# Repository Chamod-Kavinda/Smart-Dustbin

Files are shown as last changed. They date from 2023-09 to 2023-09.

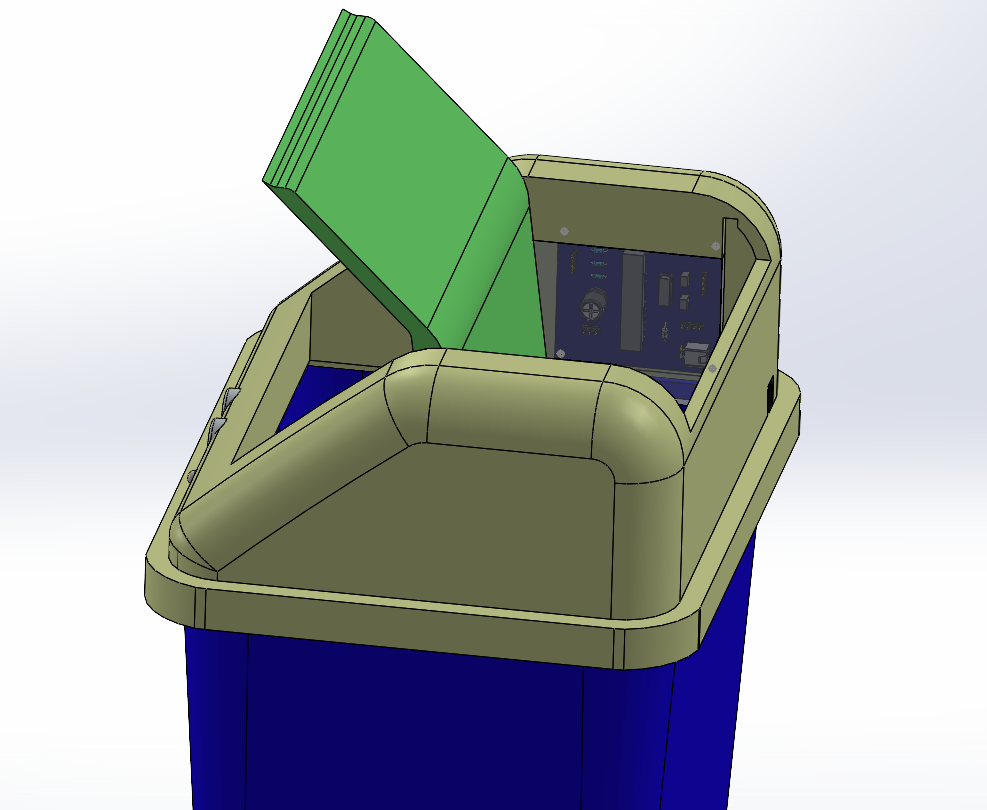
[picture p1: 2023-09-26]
Enclosure Design files/3D Design/A3.png

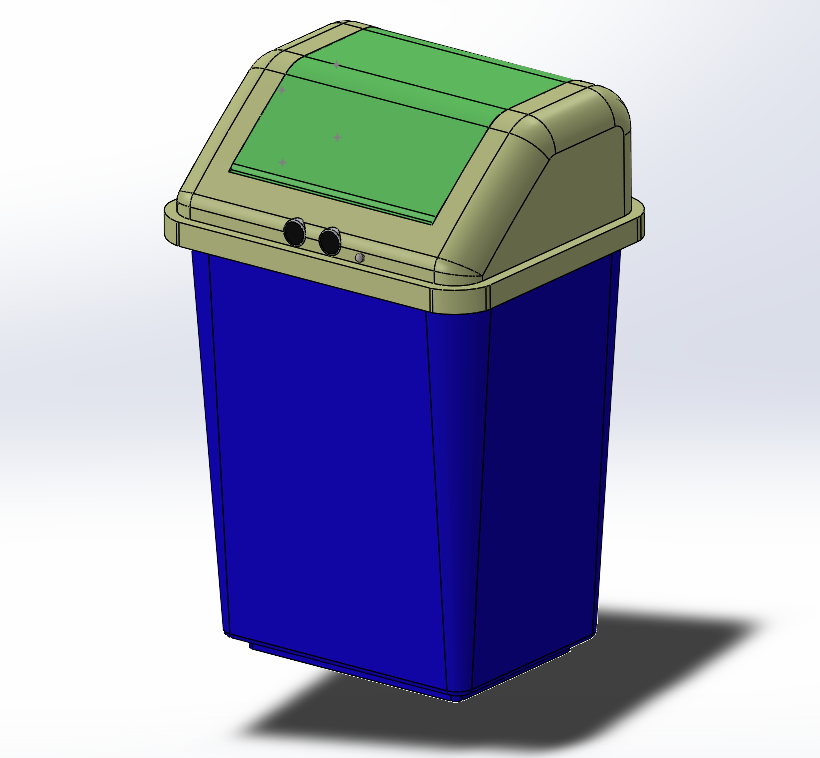
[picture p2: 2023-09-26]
Enclosure Design files/3D Design/A1.png

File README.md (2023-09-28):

# Smart Dustbin

## Introduction

The Smart Dustbin is an innovative waste management solution designed to provide convenience, hygiene, and sustainability in managing waste. This project utilizes ultrasonic sensors, a microcontroller, an RGB LED, and a servo motor to create a smart dustbin that opens automatically when someone approaches and alerts users when it's time to empty it.

## Features

- **Automatic Lid Opening**: The dustbin's lid opens automatically when a user approaches, reducing the need for physical contact and promoting hygiene.

- **Garbage Fill Level Indicator**: An RGB LED indicates the garbage fill level with colors (green, yellow, and red) so users know when it's time to empty the bin.

- **Manual Override**: Users can manually open and close the lid if needed.

[Final Report](https://github.com/Chamod-Kavinda/Smart-Dustbin/blob/main/Final%20Report.pdf)

### Schematic Design
Schematic

### PCB Design
pcb

### Solidwork Designs
Solidwork Design

### Final Product
Final Product

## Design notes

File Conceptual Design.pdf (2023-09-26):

## Department of Electronic and Telecommunication Engineering University of Moratuwa

## EN2160 – Electronic Design Realization


## Conceptual Design Report – Smart Dustbin

Name: Kavinda W.M.C.

### Index Number: 200301D

### 7th of June 2023

### 1. Introducon

This report presents the conceptual design of a smart dustbin, an innovave soluon that incorporates advanced technology for automac opening and closing. The aim of this design is to provide users with a convenient and hygienic waste disposal experience. By eliminang the need for manual operaon, the smart dustbin enhances efficiency and user convenience. This brief introducon provides an overview of the report, which explores the enclosure design and block diagrams, highlighng the importance of user feedback and customizaon opons. The report serves as a foundaon for further development, showcasing the potenal of the smart dustbin to revoluonize waste management.

### 2. List of members who contributed to the Design Driven Innovaon

1. Anuki Pasqual | 200445V
2. Tharusha Pathirana | 200449L
3. Navindu Gunawardena | 200201V
4. Peshala Gunathilaka | 200439G
5. Lasitha Jananjaya | 200650U
6. Chehal Jayasuriya | 200262G
7. Malanban Kuganenthiran 200373X

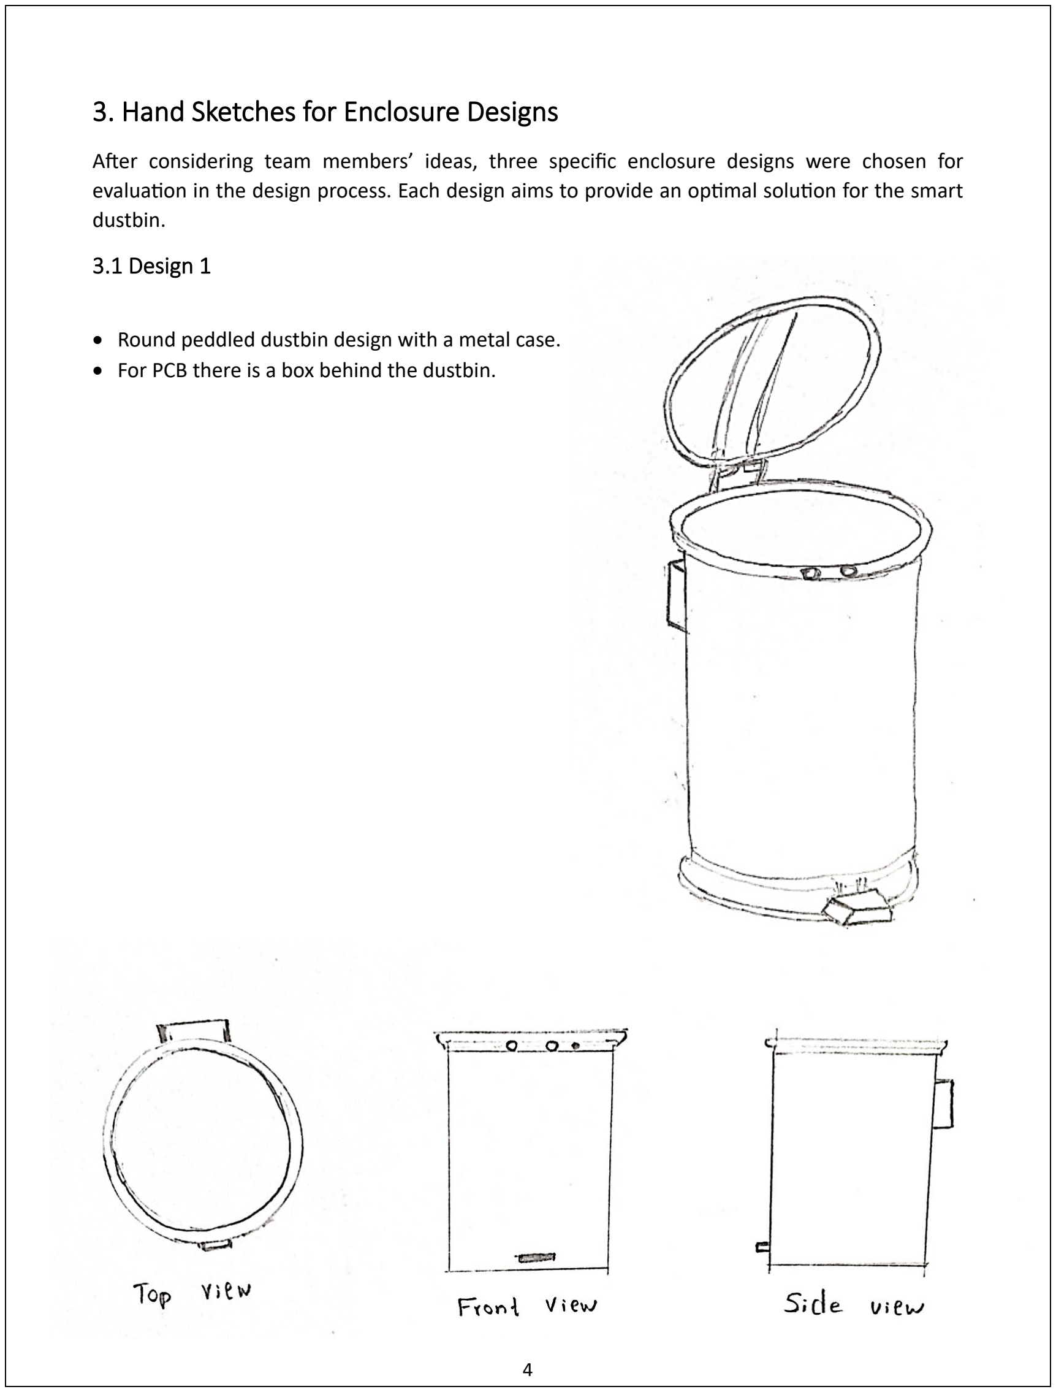
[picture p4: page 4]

### 3. Hand Sketches for Enclosure Designs

Aer considering team members’ ideas, three specific enclosure designs were chosen for evaluaon in the design process. Each design aims to provide an opmal soluon for the smart dustbin.
3.1 Design 1
- Round peddled dustbin design with a metal case.
- For PCB there is a box behind the dustbin.

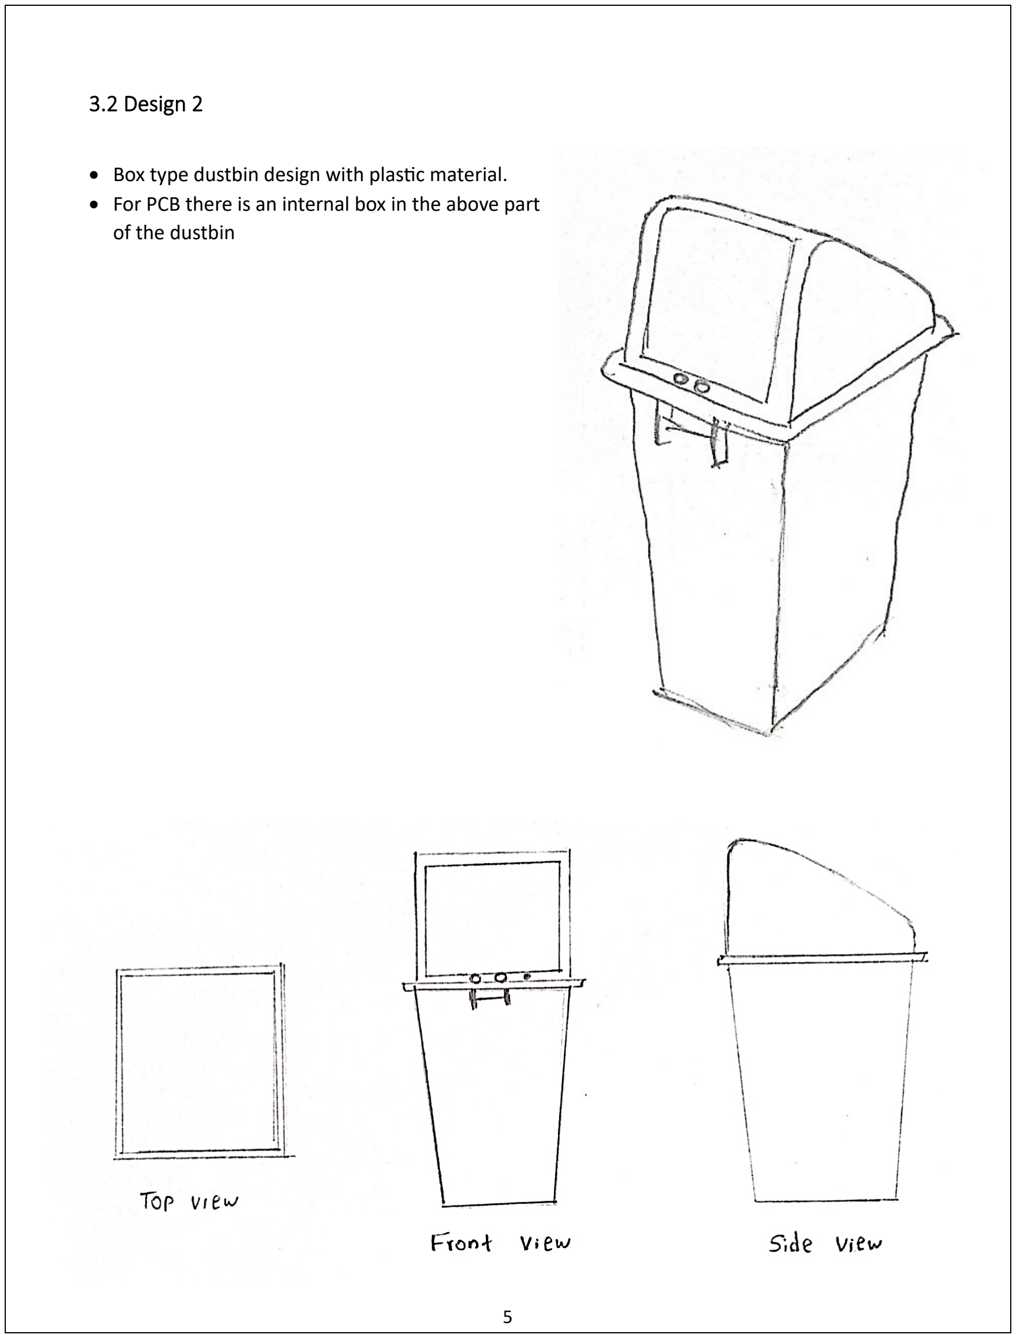
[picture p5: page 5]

3.2 Design 2

- Box type dustbin design with plasc material.
- For PCB there is an internal box in the above part of the dustbin

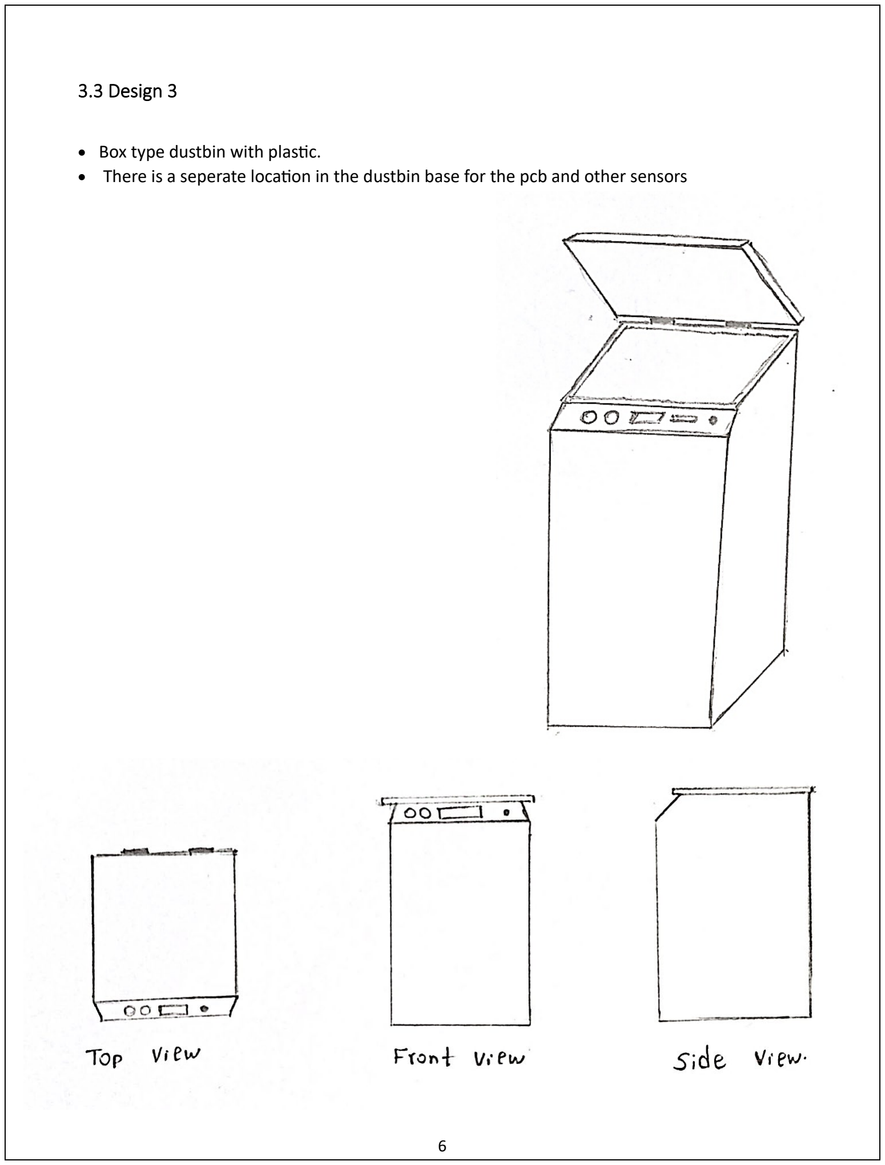
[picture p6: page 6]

3.3 Design 3

- Box type dustbin with plasc.
- There is a seperate locaon in the dustbin base for the pcb and other sensors

### 4. Block Diagrams for Circuit Designs

In the smart dustbin project context, there are opons to consider for the circuit design: power supply, sensor technologies, and lid opening mechanisms. These opons were thoroughly reviewed and evaluated with the group, considering the specific components required and the desired funconality of the smart dustbin. The group's careful assessment allowed for the selecon of the most suitable opons that align with the project's design goals and objecves. 4.1 Design 1

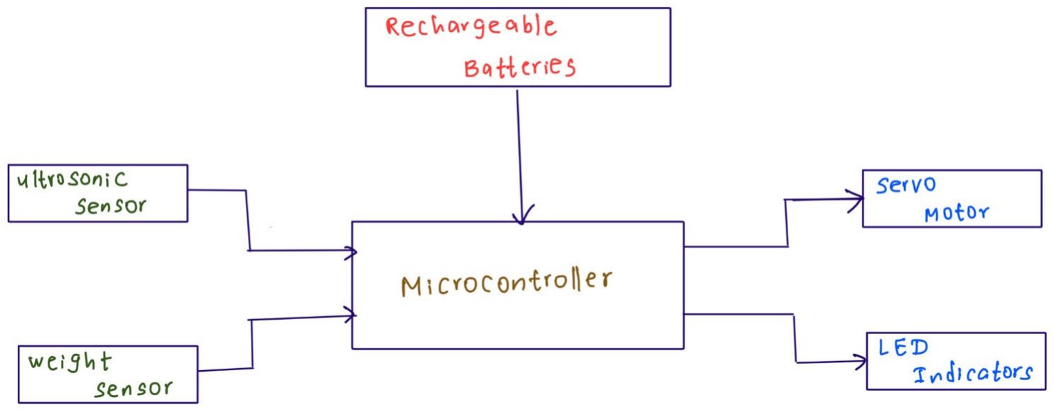
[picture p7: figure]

- Newly added: Rechargeable bateries as a power source. Weight sensor for measuring the content of the bin.
- Removed: One ultrasonic sensor

4.2 Design 2

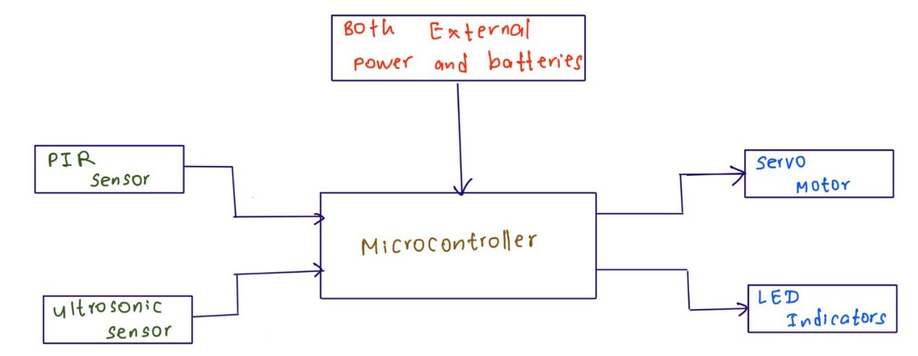
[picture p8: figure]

- Newly added: Bateries as a power source. PIR sensor for moon detecon.
- Removed: One ultrasonic sensor

4.3 Design 3

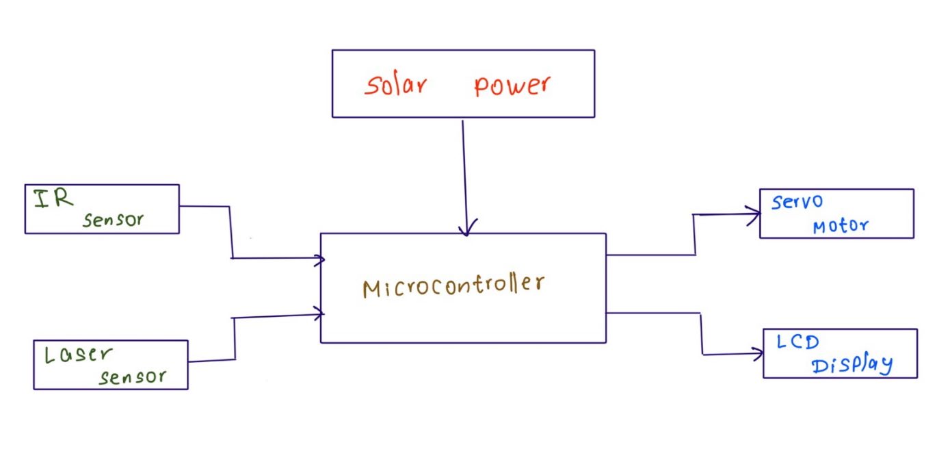
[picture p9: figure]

- Newly added: Solar power as the primary power source. IR sensor for moon detecon.
Laser sensor for measuring the content of the bin.
- Removed: | Two ultrasonic sensors
| External power source
| LED indicators

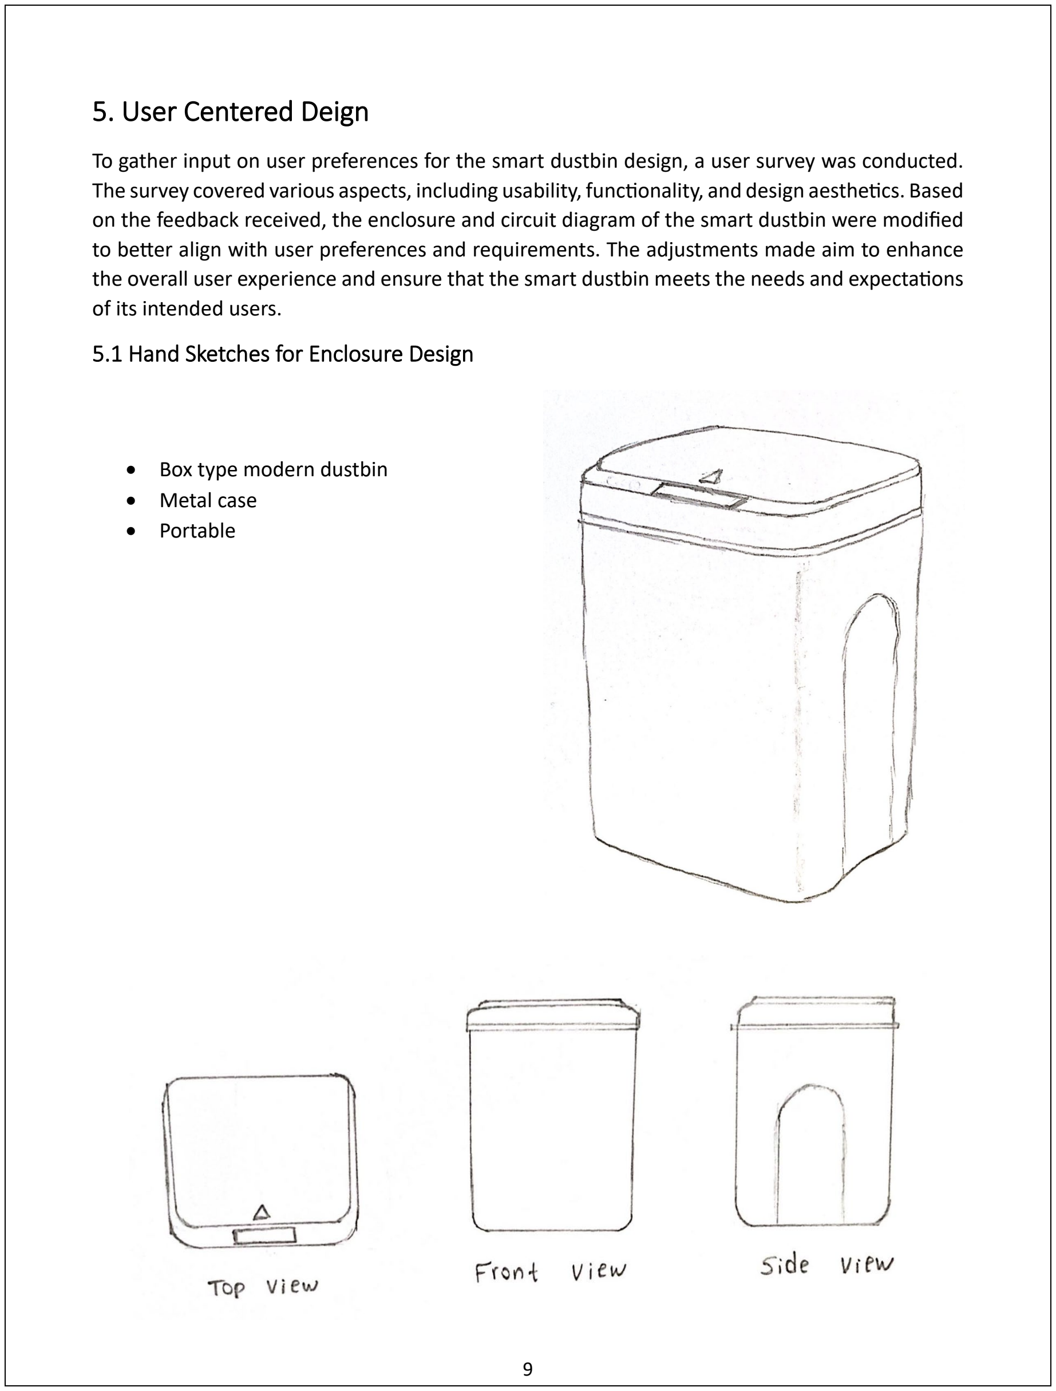
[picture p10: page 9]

### 5. User Centered Deign

To gather input on user preferences for the smart dustbin design, a user survey was conducted. The survey covered various aspects, including usability, funconality, and design aesthecs. Based on the feedback received, the enclosure and circuit diagram of the smart dustbin were modified to beter align with user preferences and requirements. The adjustments made aim to enhance the overall user experience and ensure that the smart dustbin meets the needs and expectaons of its intended users.
5.1 Hand Sketches for Enclosure Design
- Box type modern dustbin
- Metal case
- Portable

5.2 Block Diagram for Circuit Design

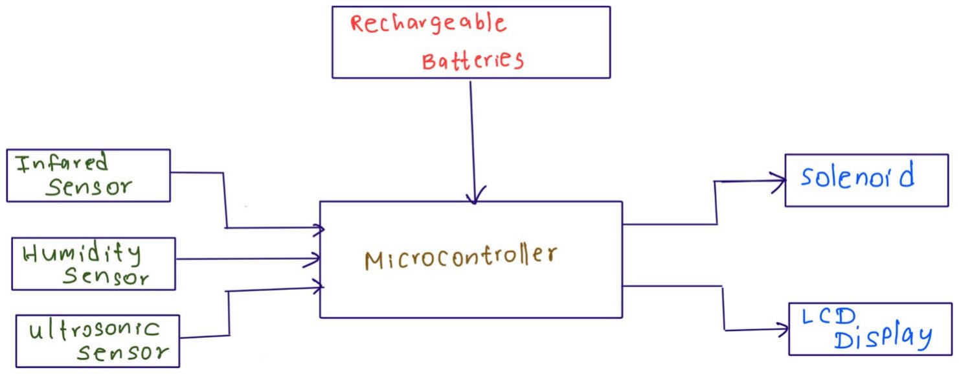
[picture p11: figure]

- Newly added: Rechargeable bateries. IR sensor for moon detecon.
Ultrasonic sensor for measuring the content of the bin. Solenoid for lid open mechanism
- Removed: | Two ultrasonic sensors
| External power source
| LED indicators
| Servo motor

### 6. Selecon Matrix

6.1 Evaluaon Criteria for Enclosures
1. Aesthecs: Assess the visual appeal and overall design harmony of the enclosure.
2. Funconality: Evaluate how well the enclosure accommodates the waste disposal process and ease of use.
3. Durability: Examine the materials and construcon of the enclosure for long-lasng performance and resistance to wear and tear.
4. Weather Resistance: Consider the enclosure's ability to withstand outdoor condions, such as rain, sunlight, and temperature fluctuaons.
5. Accessibility: Evaluate how easily users can interact with the smart dustbin, including opening and closing mechanisms, sensor placement, and user interface.
6. Size and Space Efficiency: Assess the enclosure's dimensions in relaon to the available space for placement and storage efficiency.
7. Safety: Consider any safety features incorporated into the enclosure design, such as childproof mechanisms or sensor-based obstacle detecon.
8. Integraon: Evaluate how well the enclosure design integrates with the surrounding environment, whether it is a residenal, commercial, or public seng.

The following Table depicts the marks given for each point (out of 10)
Criteria | Design 1 | Design 2 | Design 3 | User Centered Design
Aesthecs | 8 | 7 | 6 | 9
Funconality | 7 | 6 | 7 | 8
Durability | 7 | 8 | 9 | 7
Weather Resistance | 7 | 8 | 7 | 7
Accessibility | 6 | 8 | 8 | 9
Size and Space Efficiency | 9 | 6 | 7 | 9
Safety | 5 | 6 | 7 | 8
Integraon | 6 | 7 | 9 | 8
Total Marks | 55 | 56 | 60 | 65

Based on the aforemenoned criteria, it is evident that the user centered design received the highest score, making it the selected choice to proceed.

6.2 Evaluaon Criteria for Circuit Design
1. Funconality: Assess the overall funconality and performance of the circuit design, ensuring that it accurately detects and responds to the waste disposal requirements.
2. Power Efficiency: Evaluate the circuit design's power consumpon and efficiency to ensure opmal energy usage and batery life.
3. Sensor Integraon: Assess how well the circuit design integrates and interfaces with the various sensors used in the smart dustbin, such as ultrasonic sensors, weight sensors, or proximity sensors.
4. Communicaon: Evaluate the communicaon protocols and interfaces used in the circuit design, ensuring seamless data transmission between the sensors, microcontroller, and other components.
5. Safety: Consider any safety features implemented in the circuit design, such as overcurrent protecon, voltage regulaon, or short-circuit prevenon mechanisms.
6. Reliability: Evaluate the reliability and robustness of the circuit design to ensure consistent and accurate performance under different operang condions.
7. Scalability: Assess the circuit design's ability to accommodate future upgrades or addions, allowing for potenal expansion or integraon of addional features.
8. Cost-effecveness: Consider the overall cost of the circuit design, including component selecon and manufacturing consideraons, to ensure a balance between funconality and affordability.

The following Table depicts the marks given for each point (out of 10)
Criteria | Design 1 | Design 2 | Design 3 | User Centered Design
Funconality | 8 | 7 | 8 | 9
Power Efficiency | 7 | 9 | 5 | 7
Sensor Integraon | 6 | 7 | 8 | 9
Communicaon | 8 | 8 | 8 | 8
Safety | 8 | 8 | 6 | 9
Reliability | 6 | 6 | 8 | 9
Scalability | 9 | 9 | 9 | 8
Cost-effecveness | 7 | 8 | 6 | 5
Total Marks | 59 | 62 | 58 | 64

Based on the aforemenoned criteria, it is evident that the user centered design received the highest score, making it the selected choice to proceed.

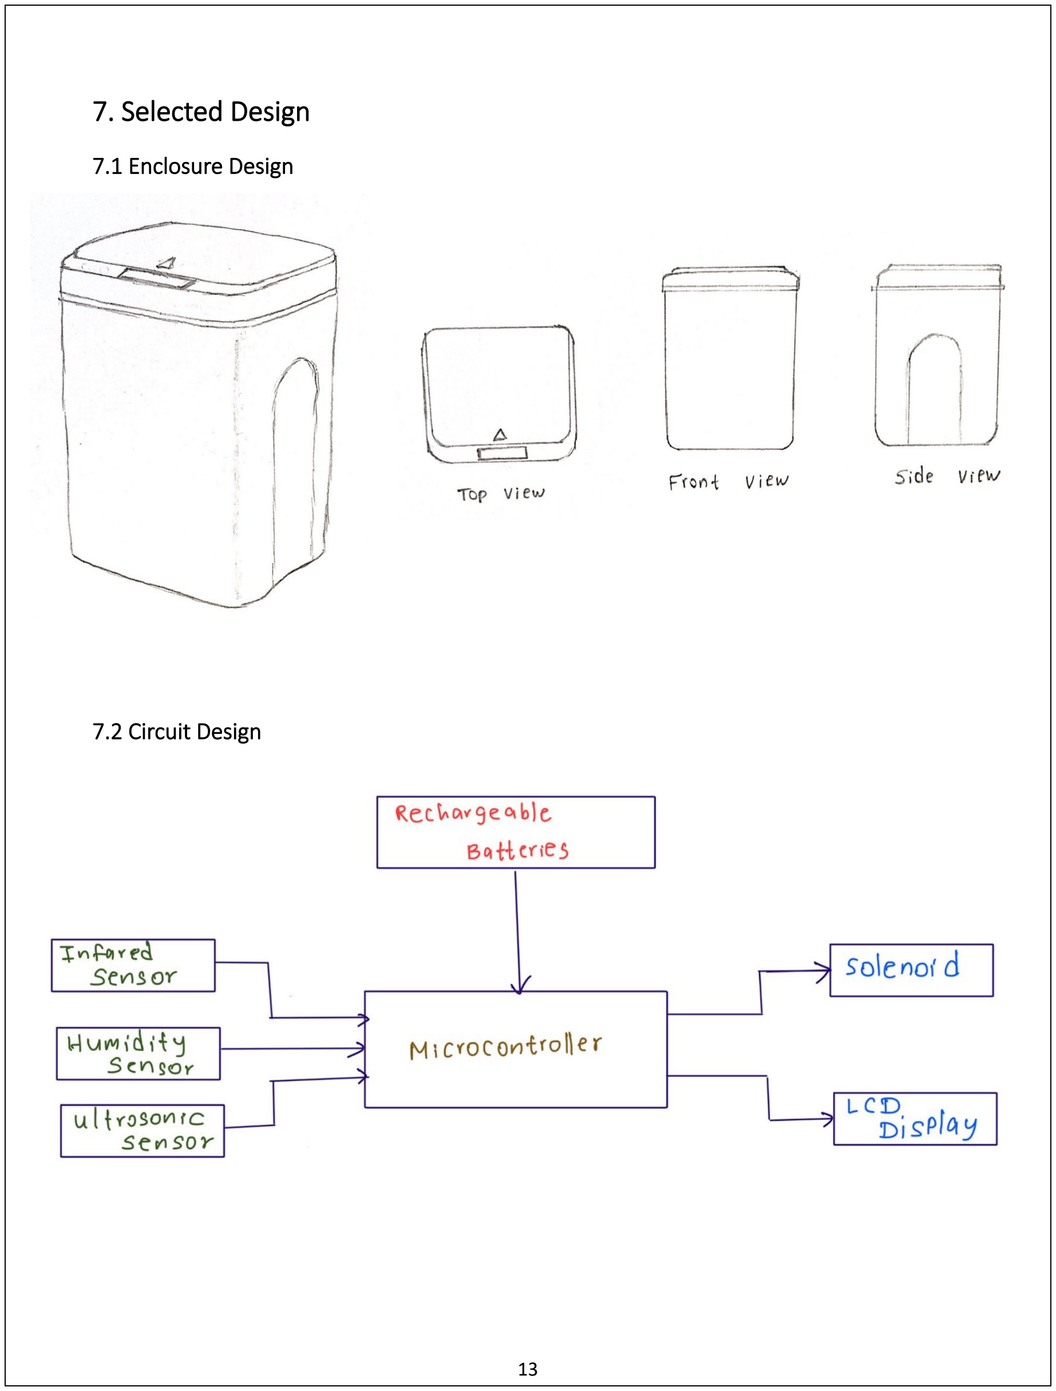
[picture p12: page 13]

### 7. Selected Design

7.1 Enclosure Design

7.2 Circuit Design

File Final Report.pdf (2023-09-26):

## Department of Electronic and Telecommunication Engineering University of Moratuwa

## EN2160 – Electronic Design Realization


## Final Report – Smart Dustbin

Name: Kavinda W.M.C.

### Index Number: 200301D

| 25th of July 2023

### Table of Contents

### Abstract

The Smart Dustbin project introduces an innovave waste management soluon designed to enhance convenience, hygiene, and sustainability. This project focuses on creang a dustbin with automac opening and a level sensor, revoluonizing the tradional waste disposal process. By incorporang ultrasonic sensor technology, the smart dustbin can detect proximity and trigger the lid to open automacally when someone approaches, reducing physical contact and promong sanitaon. Addionally, the bin ulizes a level sensor to connually monitor the garbage level and indicate to the user when it approaches full capacity, prevenng overfilling. This report presents the development and features of the smart dustbin, highlighng its contribuons to a cleaner and healthier environment while making waste disposal an efficient and hands-free experience.

### Introducon

In a world increasingly focused on sustainability and improved quality of life, waste management emerges as a crucial challenge. Tradional waste disposal methods and convenonal dustbins have long served their purpose, but they lack the efficiency and convenience required for modern living. To address this need, the Smart Dustbin project introduces an innovave soluon that elevates waste management to new heights.
The primary goal of this project is to develop a smart dustbin that offers a hands-free, hygienic, and sustainable approach to waste disposal. By incorporang advanced sensor technology, the smart dustbin opens automacally when a user approaches, reducing physical contact and minimizing the risk of contaminaon. An ultrasonic sensor serves as the key element for detecng proximity and triggering the lid's smooth and gradual opening.
Furthermore, the smart dustbin boasts a level sensor that constantly monitors the garbage fill level with remarkable accuracy and reliability. LED indicators change color as the garbage level increases, providing users with a visual cue for mely waste disposal and prevenng overfilling. This report delves into the design, development, and features of the smart dustbin, highlighng its potenal to transform waste management pracces. By promong touchless interacon, reducing waste overflow, and encouraging responsible waste disposal habits, the smart dustbin takes a significant step toward a cleaner, healthier, and more sustainable future.

### 1. Product Descripon and Specificaons

The Smart Dustbin is a revoluonary waste management soluon designed to offer convenience, hygiene, and sustainability in disposing of garbage. This innovave dustbin incorporates advanced sensor technology to create a touchless and efficient waste disposal experience. It is constructed using plasc material, ensuring durability and longevity. The smart dustbin has a compact size, measuring 20cm x 15cm x 35cm, and features a capacity of 10 liters, making it suitable for home use and other sengs with frequent waste generaon.
1.1. Specificaons
- Material: HDPE (High-density polyethylene)
- Size: 20cm x 15cm x 35cm
- Capacity: 10 liters
- Shape: Square Dustbin
- Color: Blue, green, and yellow
- Power Source: 5V 1A power adapter
1.2. Key Features
- Automac Opening Mechanism: The Smart Dustbin is equipped with an ultrasonic sensor that detects the presence of a person near the bin. When someone approaches, the sensor triggers the automac lid opening mechanism, allowing for a hands-free waste disposal experience. This feature minimizes physical contact with the dustbin, promong hygiene and sanitaon.
- Level Sensor with LED Indicators: The dustbin is integrated with a level sensor that employs ultrasonic technology to connuously measure the garbage fill level. LED indicators on the dustbin's exterior change colors as the garbage level increases. The LED lights switch from green to yellow and eventually red, providing a visual cue to the user about the current fill level. This real-me monitoring prevents overfilling and helps users know when it's me to empty the dustbin.
- Smooth and Gradual Lid Closure: The lid of the smart dustbin is designed to open smoothly and close gradually. This ensures user safety during operaon and prevents any abrupt lid movements.
- Manual Override Feature: While the smart dustbin offers automac opening, it also includes a manual override feature. Users can open the lid manually, providing flexibility and control when needed.
- Applicaon: The Smart Dustbin is ideal for both household and public use. In homes, it provides a convenient and hygienic soluon for waste disposal, especially in kitchens and common areas. In public places such as offices, shopping centers, and parks, the smart dustbin ensures a touchless and efficient waste management system for many users.

### 2. Implementaon

2.1. Component Selecon
To bring the Smart Dustbin project to life, specific components were carefully chosen based on their performance, compability, and cost-effecveness. The selected components are as follows

### 1. Ultrasonic Sensor (HC-SR04):

The HC-SR04 Ultrasonic sensor is ulized as the primary component for both the automac opening mechanism and the level sensor. It accurately detects the distance between the sensor and an object by measuring the me taken for sound waves to bounce back. This informaon is crucial for triggering the lid's automac opening when someone approaches the dustbin and for monitoring the garbage fill level inside the bin.

### 2. Microcontroller Unit (MCU) - ATmega328P:

The ATmega328P microcontroller unit serves as the brain of the smart dustbin. It receives and processes data from the ultrasonic sensors, controls the actuator for the lid mechanism, and manages the LED indicators based on the garbage fill level. The ATmega328P was chosen for its versality, performance, and compability with the selected components.

### 3. LED Indicators - One RGB LED:

A single RGB (Red, Green, Blue) LED is chosen as the indicator for the garbage fill level. By controlling the intensity of the three colors, the LED can display various colors, each corresponding to a different fill level. Green indicates a low fill level, yellow indicates a medium fill level, and red indicates a high fill level, prompng users to empty the bin.

### 4. Actuator - SG90 9g Micro Servo Motor:

The SG90 9g Micro Servo Motor is the actuator responsible for opening and closing the dustbin lid. When triggered by the MCU, the servo motor rotates to li the lid, providing a smooth and gradual opening. The servo motor is suitable for this applicaon due to its compact size, precise control, and sufficient torque to handle the lid's weight.

### 5. Power Supply Unit:

To power the smart dustbin and its components, a 5V 1A power adapter has been chosen. This power supply unit provides stable voltage and sufficient current to ensure the proper operaon of all the selected components without any performance issues.

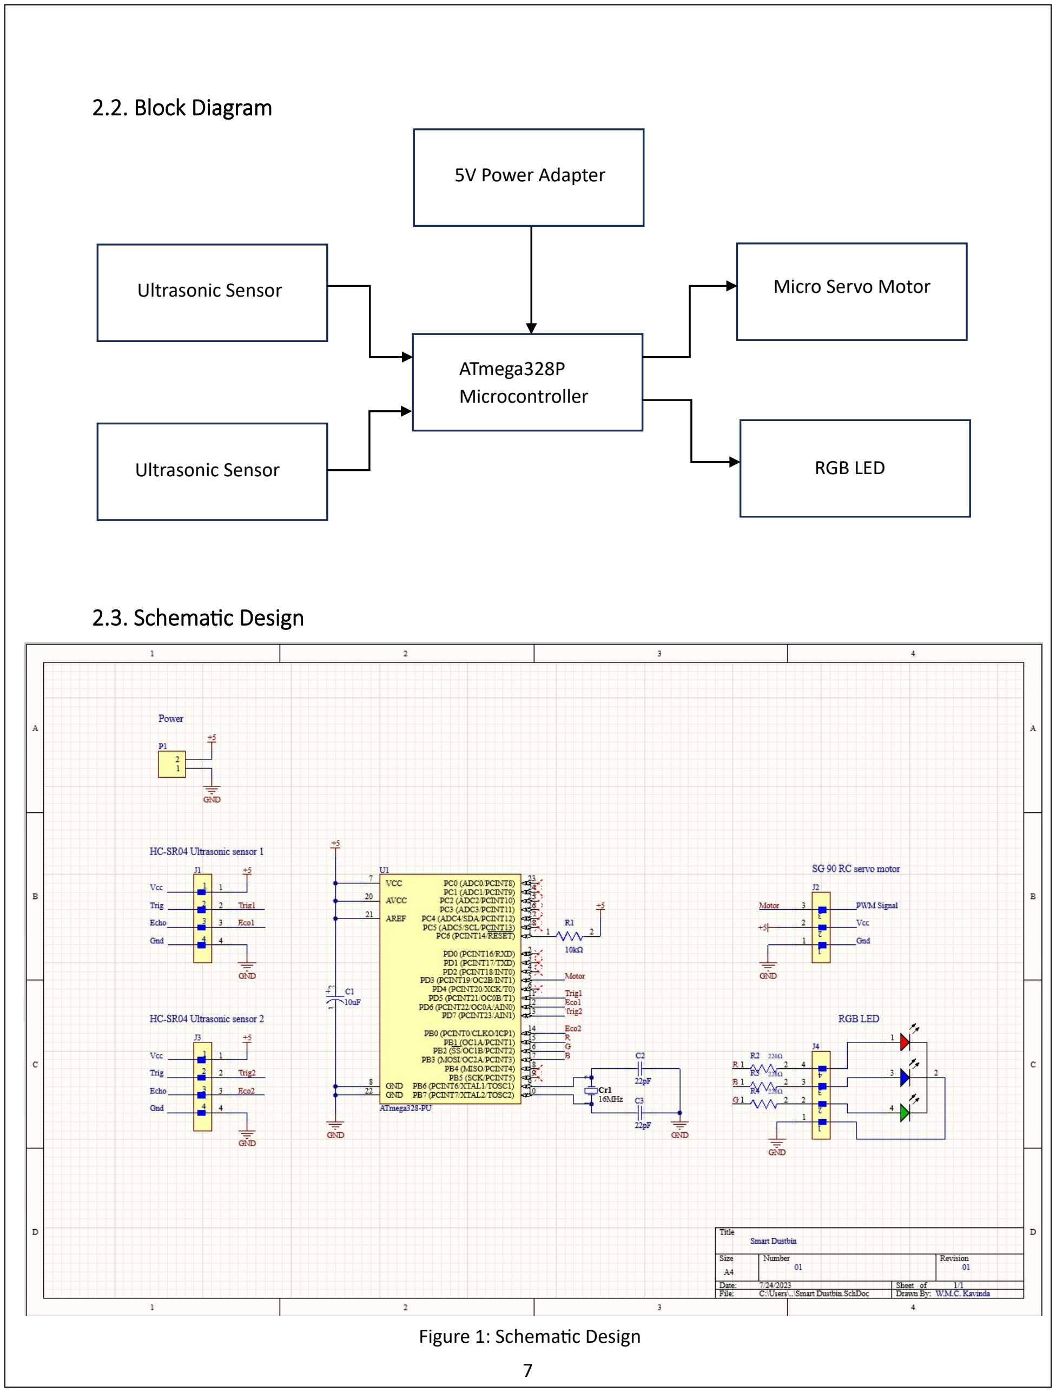
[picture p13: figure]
2.2. Block Diagram; 2.3. Schemac Design; ATmega328P Microcontroller; Ultrasonic Sensor; Micro Servo Motor; RGB LED; 5V Power Adapter; Figure 1: Schemac Design
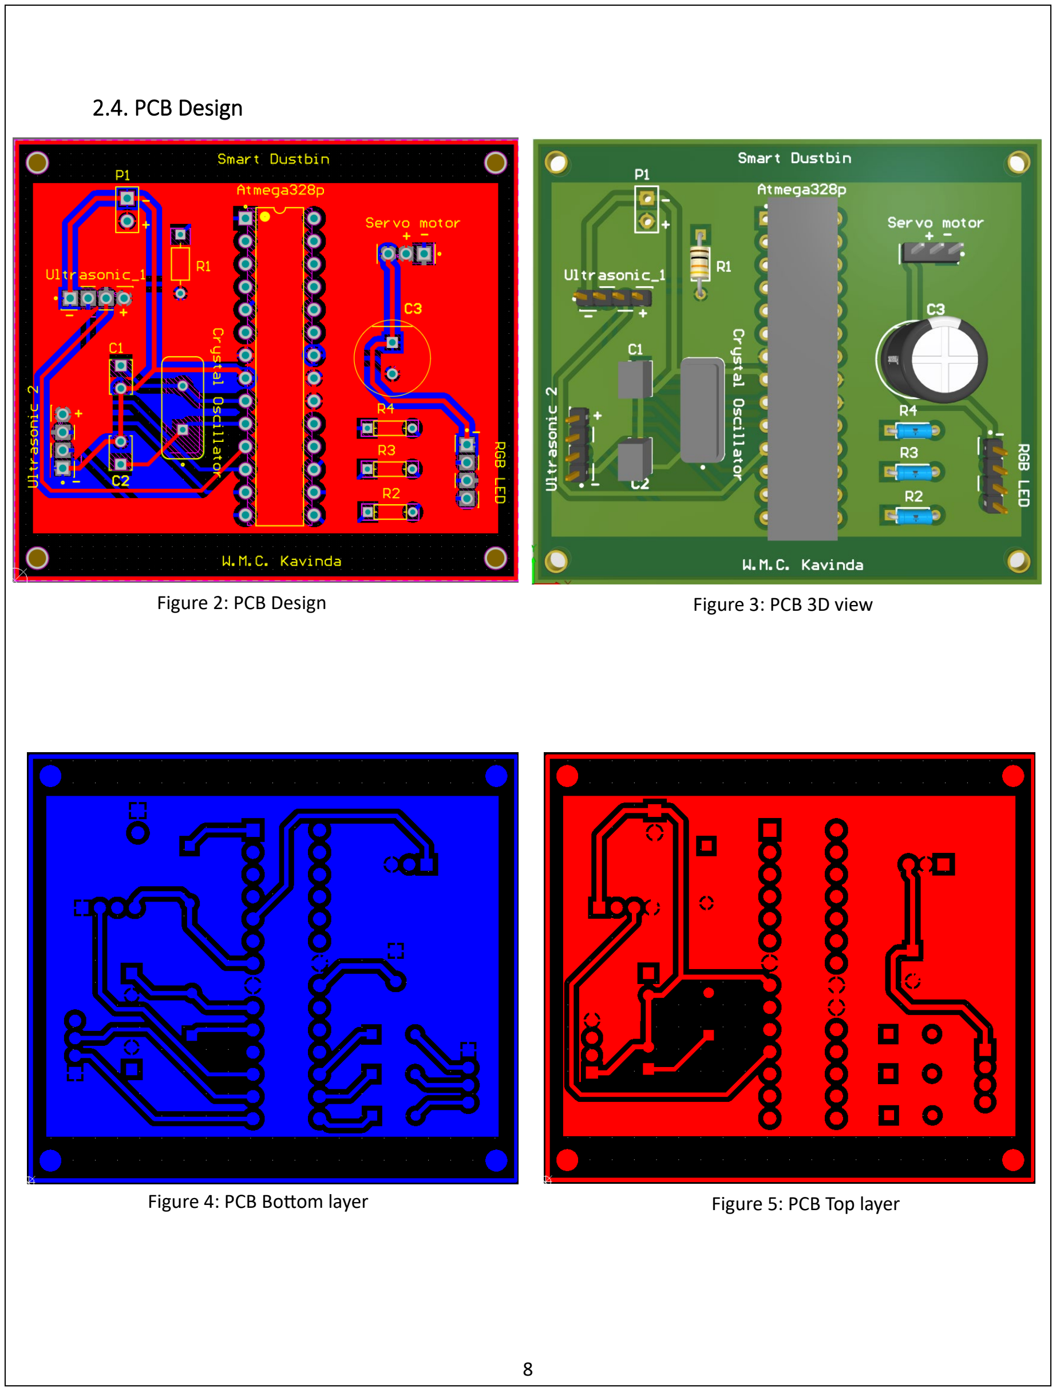
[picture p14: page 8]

2.4. PCB Design
Figure 2: PCB Design | Figure 3: PCB 3D view
Figure 4: PCB Botom layer | Figure 5: PCB Top layer

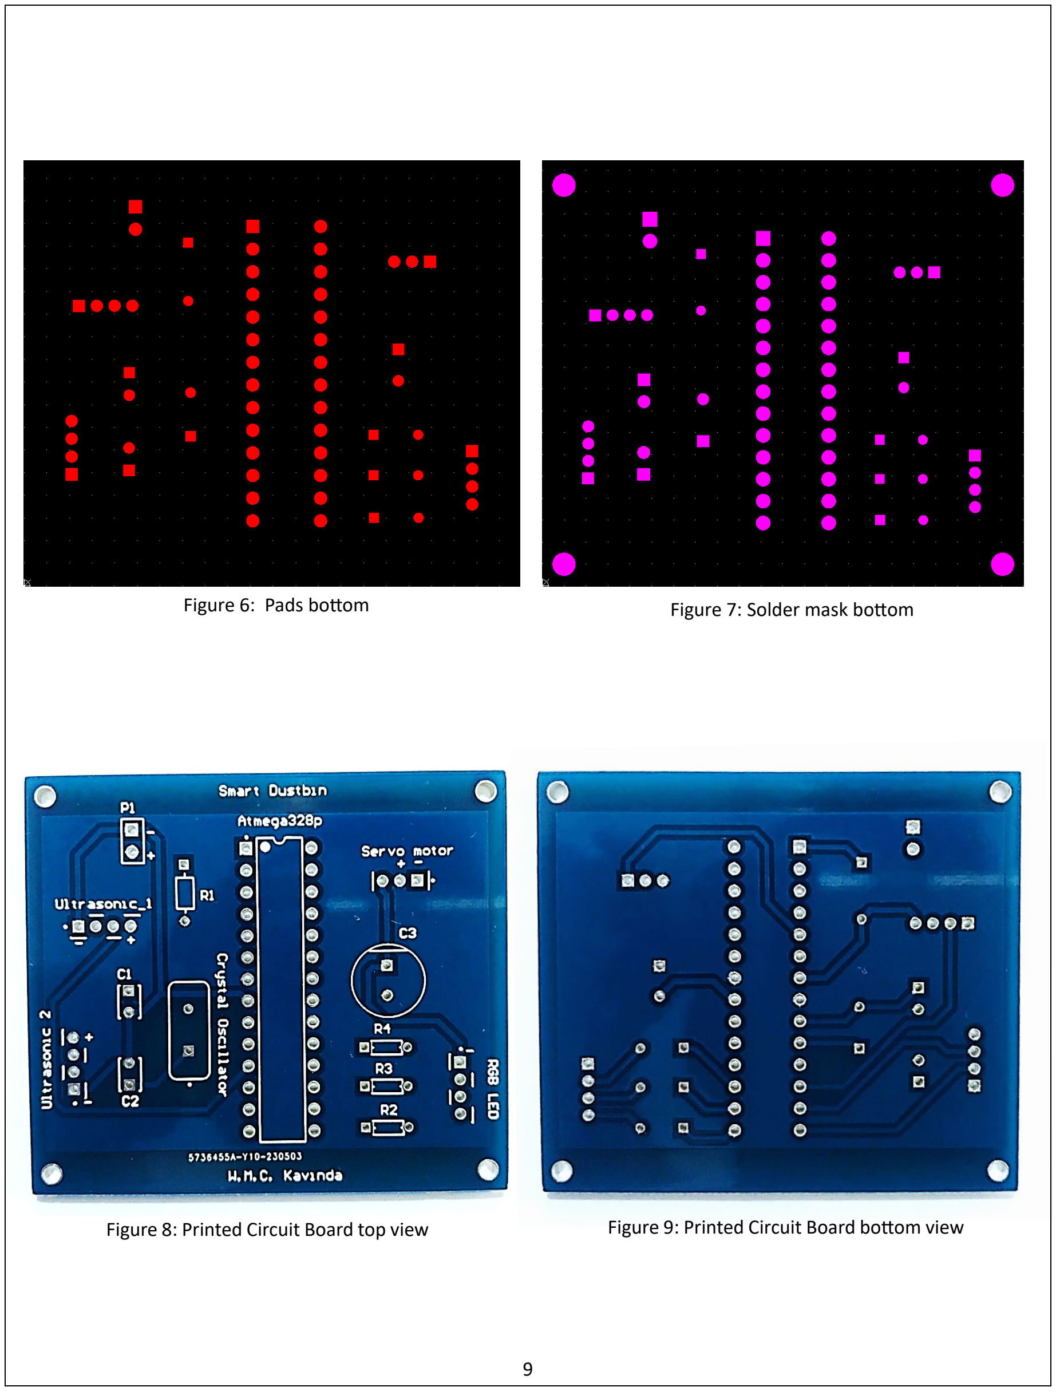
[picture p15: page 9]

Figure 6: Pads botom | Figure 7: Solder mask botom
Figure 8: Printed Circuit Board top view | Figure 9: Printed Circuit Board botom view

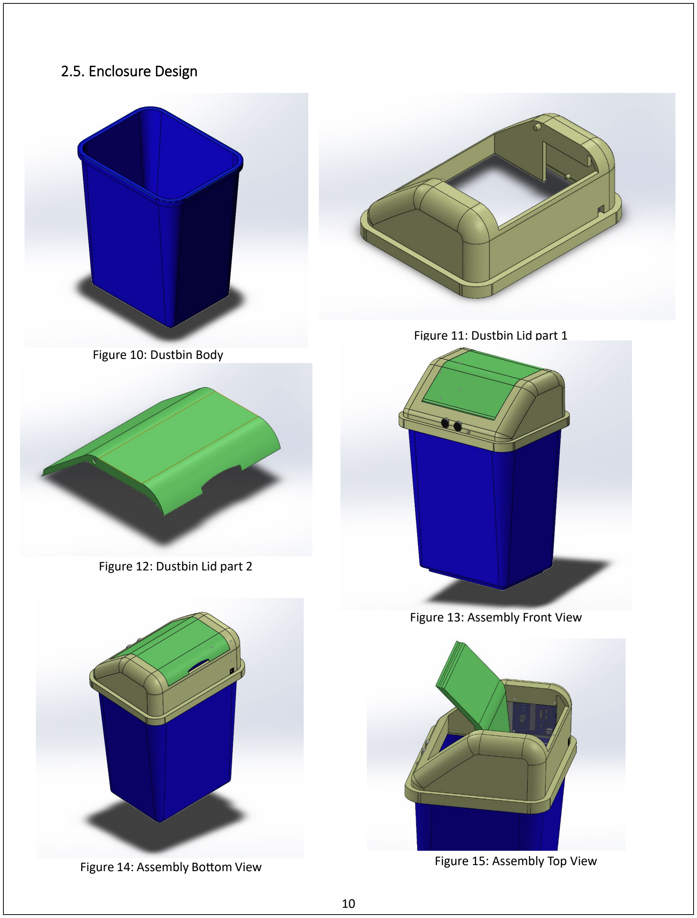
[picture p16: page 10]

2.5. Enclosure Design

Figure 10: Dustbin Body

Figure 11: Dustbin Lid part 1

Figure 12: Dustbin Lid part 2

Figure 13: Assembly Front View

Figure 14: Assembly Botom View | Figure 15: Assembly Top View

2.6. Soware Implementaon

#include <Servo.h>

// constants won't change
const int TRIG_PIN1 = 7; // Arduino pin connected to Ultrasonic Sensor's TRIG pin const int ECHO_PIN1 = 8; // Arduino pin connected to Ultrasonic Sensor's ECHO pin const int TRIG_PIN2 = 5; // Arduino pin connected to Ultrasonic Sensor's TRIG pin const int ECHO_PIN2 = 6; // Arduino pin connected to Ultrasonic Sensor's ECHO pin const int SERVO_PIN = 3; // Arduino pin connected to Servo Motor's pin
const int DISTANCE_THRESHOLD = 20; // centimeters
Servo servo; // create servo object to control a servo
// variables will change:
float duration_1, distance_1;
float duration_2, distance_2;
int red_LED = 10;
int green_LED = 11;
int blue_LED = 9;
void setup() {
Serial.begin(9600); // initialize serial port pinMode(TRIG_PIN1, OUTPUT); // set arduino pin to output mode pinMode(ECHO_PIN1, INPUT); // set arduino pin to input mode pinMode(TRIG_PIN2, OUTPUT); // set arduino pin to output mode pinMode(ECHO_PIN2, INPUT); // set arduino pin to input mode pinMode(red_LED, OUTPUT);
pinMode(green_LED, OUTPUT);
pinMode(blue_LED, OUTPUT);
servo.attach(SERVO_PIN); // attaches the servo on pin 9 to the servo object servo.write(0);
analogWrite(red_LED, 0);
analogWrite(green_LED, 255);
analogWrite(blue_LED, 0);
}
void loop() {
// generate 10-microsecond pulse to TRIG pin digitalWrite(TRIG_PIN1, HIGH); delayMicroseconds(10);
digitalWrite(TRIG_PIN1, LOW);
duration_1 = pulseIn(ECHO_PIN1, HIGH); // calculate the distance
distance_1 = 0.017 * duration_1; digitalWrite(TRIG_PIN2, HIGH); delayMicroseconds(10);
digitalWrite(TRIG_PIN2, LOW); duration_2 = pulseIn(ECHO_PIN2, HIGH); // calculate the distance
distance_2 = 0.017 * duration_2;
if (distance_1 < DISTANCE_THRESHOLD) { servo.write(90); // rotate servo motor to 90 degree

analogWrite(red_LED, 0);
analogWrite(green_LED, 0); analogWrite(blue_LED, 255); delay(3000);
}
else {
servo.write(0); // rotate servo motor to 0 degree if (distance_2 < 10) {
analogWrite(red_LED, 255); analogWrite(green_LED, 0); analogWrite(blue_LED, 0);
}
else if (distance_2 < 20) { analogWrite(red_LED, 255); analogWrite(green_LED, 200); analogWrite(blue_LED, 0);
}
else {
analogWrite(green_LED, 255); analogWrite(red_LED, 0);
analogWrite(blue_LED, 0);
}
}
delay(300);
}

### 3. Instrucons for Assembly

Assembling the Smart Dustbin requires careful handling of the components and systemac integraon of the circuit. Follow the step-by-step instrucons below to ensure a successful assembly.
Step 1: Gather Components
Gather all the necessary components for the smart dustbin assembly, including the Smart Dustbin enclosure, PCB with soldered MCU (ATmega328P) and other supporng components, two HCSR04 Ultrasonic Sensors, RGB LED, SG90 9g Micro Servo Motor, wires, and the 5V 1A power adapter.
Step 2: Prepare the PCB
Ensure that the MCU (ATmega328P) is properly soldered onto the PCB board, with all necessary supporng components like capacitors and resistors in place.
Step 3: Connect the Ultrasonic Sensors
Mount the HC-SR04 Ultrasonic Sensors inside the Smart Dustbin enclosure at an appropriate posion for detecng proximity. Connect the ultrasonic sensor's wires (VCC, GND, Trig, and Echo) to the corresponding pins on the MCU board. Use wires for this purpose.
Step 4: Connect the RGB LED
Place the RGB LED inside the Smart Dustbin enclosure at a visible locaon. Connect the RGB LED's wires (R, G, and B pins) to the three 220Ω resistors on the PCB board to limit the current flow, and then connect the resistors to the corresponding digital output pins on the MCU board using wires.
Step 5: Connect the Servo Motor
Mount the SG90 9g Micro Servo Motor inside the Smart Dustbin enclosure in such a way that it can open and close the lid effecvely. Connect the servo motor's wires (VCC, GND, and Signal) to the corresponding pins on the MCU board. Use wires for this connecon.
Step 6: Power Supply
Connect the 5V 1A power adapter to the power input of the PCB board.
Step 7: Test the Smart Dustbin
Power up the smart dustbin by plugging in the 5V 1A power adapter. Test the funconality of the smart dustbin,
- Approach the dustbin, and the ultrasonic sensor should trigger the servo motor to open the lid automacally.
- The RGB LED should display different colors based on the garbage fill level (green for low, yellow for medium, and red for high).

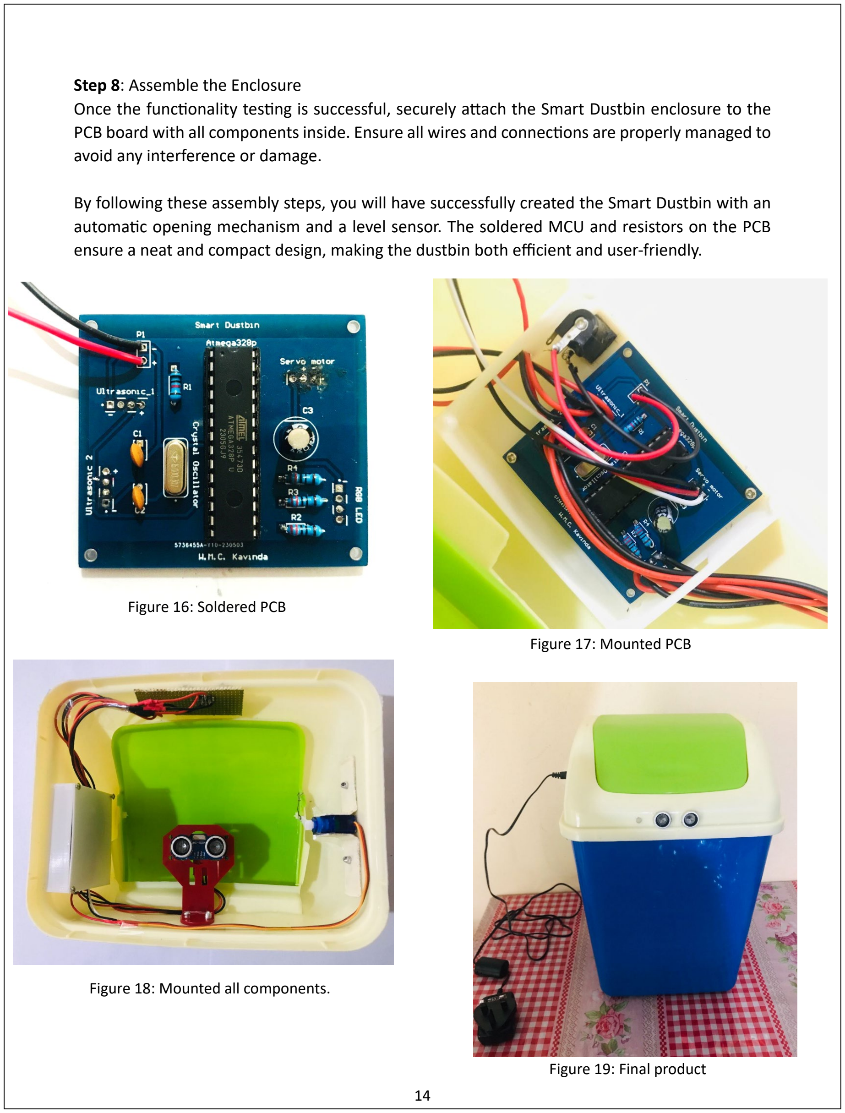
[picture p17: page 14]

Step 8: Assemble the Enclosure
Once the funconality tesng is successful, securely atach the Smart Dustbin enclosure to the PCB board with all components inside. Ensure all wires and connecons are properly managed to avoid any interference or damage.

By following these assembly steps, you will have successfully created the Smart Dustbin with an automac opening mechanism and a level sensor. The soldered MCU and resistors on the PCB ensure a neat and compact design, making the dustbin both efficient and user-friendly.

Figure 16: Soldered PCB
Figure 17: Mounted PCB

Figure 18: Mounted all components.

Figure 19: Final product

### 4. Tesng the Product Funconality

To test the funconality of the Smart Dustbin, follow these steps.

Step 1: Power On
Connect the 5V 1A power adapter to the power input of the PCB board.
Power on the Smart Dustbin by plugging in the power adapter.
Step 2: Automac Lid Opening
Approach the Smart Dustbin closely, ensuring that the Ultrasonic Sensor can detect your presence.
The Ultrasonic Sensor should trigger the Servo Motor, causing the lid to open automacally. Verify that the lid opens smoothly and gradually in response to your proximity.
Step 3: Lid Closing
Once you have tested the automac lid opening and manual override, ensure that the lid closes smoothly and securely.
Test the responsiveness of the lid closing acon, ensuring it does not close too quickly or forcefully.
Step 4: Garbage Fill Level Indicaon
Observe the RGB LED indicators on the Smart Dustbin enclosure.
The LED should display a green light when the garbage fill level is low, indicang sufficient capacity.
As you gradually add garbage or block the Ultrasonic Sensor's path, the LED should change to yellow and then red as the garbage level increases.
Step 5: Repeat Tesng
Repeat the above steps mulple mes to ensure consistent and reliable funconality.
Pay atenon to any anomalies, such as incorrect LED indicaons or lid malfuncon.

By performing these funconality tests, you can ensure that the Smart Dustbin operates smoothly, providing an efficient, hygienic, and user-friendly waste management experience. If any issues or inconsistencies are detected during tesng, carefully review the circuit connecons and programming to recfy the problems. Once the Smart Dustbin passes all tests successfully, it is ready for use and can offer a seamless soluon for waste disposal in your home or public spaces.

### 5. Bill of Materials

5.1. Foreign Market
Item | Manufacture | Supplier | Unit price (US$) | Qty. | Total amount (US$)
ATMEGA328P-PU | Microchip Tech | LCSC | 4.25 | 1 | 4.25
28 pin IC socket | ZHOURI | LCSC | 0.0442 | 1 | 0.0442
16MHz crystal oscillator | TAITIEN Elec (https://www.lcsc.com/brand-detail/1279.html) | LCSC | 0.1 | 1 | 0.1
10 uF 50V capacitor | Nantong Jianghai | LCSC | 0.038 | 1 | 0.038
22 pF capacitor | Dersonic | LCSC | 0.0095 | 2 | 0.019
10kΩ 250mW resistor | TyoHM | LCSC | 0.0088 | 1 | 0.0088
220Ω 250mW resistor | TyoHM | LCSC | 0.0086 | 3 | 0.0258
RGB 5mm LED | TOGIALED | LCSC | 0.1319 | 1 | 0.1319
PCB | JLCPCB | JLCPCB | 0.8 | 1 | 0.8
Shipping cost + tax | | | | | 6.5
Total cost | | | | | 11.92
5.2. Local Market
Item | Supplier | Unit price (Rs) | Qty. | Total amount (Rs)
HC-SR04 Ultrasonic Sensor | Tronic.lk | 300 | 2 | 600
Micro Servo Motor SG90 | Tronic.lk | 410 | 1 | 410
5V 1A SMPS Power Adapter | Tronic.lk | 500 | 1 | 500
Connectors & wires | Tronic.lk | - | - | 250
Enclosure for PCB | Xydder | 900 | 1 | 900
Dustbin | Arpico | 850 | 1 | 850
Total cost | | | | 3510
Total cost (Rs) | = 3960.23 + 3510.00 = 7470.23

### 6. Future Developments

As technology and innovaon connue to advance, the Smart Dustbin can undergo further developments to enhance its capabilies and address emerging needs in waste management. Some potenal future developments for the Smart Dustbin include:

### 1. Internet of Things (IoT) Integraon:

Integrang the Smart Dustbin with IoT technology could enable remote monitoring and control. Users can receive real-me noficaons about the garbage fill level, lid status, and even schedule waste collecon services automacally when the bin reaches a certain capacity.

### 2. Smart Sorng and Recycling:

Future iteraons of the Smart Dustbin could incorporate smart sorng mechanisms that use arficial intelligence (AI) to idenfy recyclable materials. It could separate recyclable waste from non-recyclable waste, making recycling more efficient and reducing the environmental impact.

### 3. Solar-Powered Operaon:

Implemenng solar panels on the Smart Dustbin could enable it to harness renewable energy, reducing its dependency on the electrical grid and making it more sustainable and eco-friendlier.

### 4. Collaborave Waste Management System:

Smart Dustbins could be connected in a network, forming a collaborave waste management system. They can share data about waste levels, collecon schedules, and opmize waste collecon routes, leading to more efficient waste management pracces.

### 5. Smart Waste Composng:

Integrang composng features into the Smart Dustbin could facilitate the conversion of organic waste into nutrient-rich compost, promong sustainable waste management pracces.

As technology evolves and societal awareness about waste management increases, the Smart Dustbin has the potenal to evolve into a comprehensive waste management soluon, contribung to a cleaner and more sustainable future.

### 7. Acknowledgment

I would like to express my hearelt gratude to all those who contributed to the successful compleon of the Smart Dustbin project and the preparaon of this project report. Special thanks to my project supervisors Prof. J.A.K.S. Jayasinghe and Dr. Jayathu Samarawickrama for their valuable guidance and support. I am also thankful to my friends for their collaboraon and dedicaon. Lastly, I am grateful to my family for their unwavering encouragement throughout this endeavor. Your contribuons have been invaluable, and I am truly grateful for your assistance.

### 8. References

ATmega328P - htps://datasheet.lcsc.com/lcsc/Microchip-Tech-ATMEGA328P-PU.pdf (https://datasheet.lcsc.com/lcsc/1811121616_Microchip-Tech-ATMEGA328P-PU_C33901.pdf) HC-SR04 Ultrasonic sensor - htps://datasheetspdf.com/pdf-file/1380136/ETC/HC-SR04/1 SG90 Micro Servo motor - htps://datasheetspdf.com/pdf-file/791970/TowerPro/SG90/1 RGB LED - htps://datasheet.lcsc.com/lcsc/1912111437_TOGIALED-TJ-L5FYTXHTCYLCRGB.pdf
PCB Design - From Zero to PCB | using Alum Designer - YouTube (https://www.youtube.com/watch?v=6N2A6LtBWh0&ab_channel=Audas)

### 9. Appendix (User Manual)

9.1. Introducon
Thank you for choosing the Smart Dustbin, an innovave waste management soluon that brings convenience, hygiene, and sustainability to your daily life. This user manual provides essenal informaon on how to use and maintain your Smart Dustbin effecvely. Please read this manual carefully before operang the product.
9.2. Product Overview
The Smart Dustbin is equipped with an automac opening mechanism triggered by an ultrasonic sensor and a level sensor to monitor the garbage fill level connuously. The key features of the Smart Dustbin include:
Automac Opening: The lid opens automacally when someone approaches the dustbin, reducing the need for physical contact and promong hygiene.
Level Sensor: The Smart Dustbin employs a level sensor that connuously monitors the garbage fill level. LED indicators change color (green, yellow, and red) based on the fill level, indicang when it's me to empty the bin.
9.3. Operang Instrucons
9.3.1. Automac Lid Opening
- Approach the Smart Dustbin closely, within the detecon range of the ultrasonic sensor.
- The lid will open automacally, allowing you to dispose of garbage without touching the dustbin.
9.3.2. Garbage Fill Level Indicaon
- Observe the LED indicators on the Smart Dustbin enclosure.
- Green Light: Indicates a low garbage fill level, implying sufficient capacity.
- Yellow Light: Indicates a medium garbage fill level, reminding you that the dustbin will need emptying soon.
- Red Light: Indicates a high garbage fill level, prompng you to empty the dustbin immediately.
9.4. Maintenance
9.4.1. Cleaning
- Regularly clean the Smart Dustbin's exterior with a mild detergent and a so cloth.
- Ensure to clean the inner bucket regularly to maintain hygiene.

9.4.2. Garbage Disposal
- When the garbage fill level reaches the red LED indicaon, empty the dustbin promptly to prevent overflow.
- Use standard garbage bags or liners inside the inner bucket for easy disposal.
9.5. Safety Precauons
- Do not disassemble or modify the Smart Dustbin, as it may damage the product and void the warranty.
- Keep the Smart Dustbin away from water, moisture, and extreme heat sources.
- Avoid overloading the dustbin with excessively heavy or bulky items.
9.6. Troubleshoong
In case of any issues or concerns with the Smart Dustbin's funconality, refer to the troubleshoong secon in this manual or contact our customer support for assistance.
9.7. Warranty and Support
The Smart Dustbin comes with a limited warranty period. For warranty details and customer support, refer to the warranty card provided with the product.
9.8. Conclusion
The Smart Dustbin is designed to provide a convenient, hygienic, and sustainable waste management soluon. By following this user manual and taking proper care of the product, you can enjoy an efficient and pleasant waste disposal experience. Thank you for choosing the Smart Dustbin, and we hope it enhances your daily life while contribung to a cleaner and healthier environment.

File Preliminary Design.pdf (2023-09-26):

## Department of Electronic and Telecommunication Engineering University of Moratuwa

## EN2160 – Electronic Design Realization


## Preliminary Design Report – Smart Dustbin

Name: Kavinda W.M.C.

### Index Number: 200301D

### 16th of June 2023

## Contents

### 1. Introducon

This preliminary design report introduces a groundbreaking concept the smart dustbin. This innovave soluon integrates cung-edge technology to automate the opening and closing of the dustbin, aiming to offer users a convenient and hygienic waste disposal experience. By eliminang the need for manual operaon, this intelligent dustbin enhances efficiency and user convenience, transforming the way we manage waste.

### 2. Schemac of the implemented design

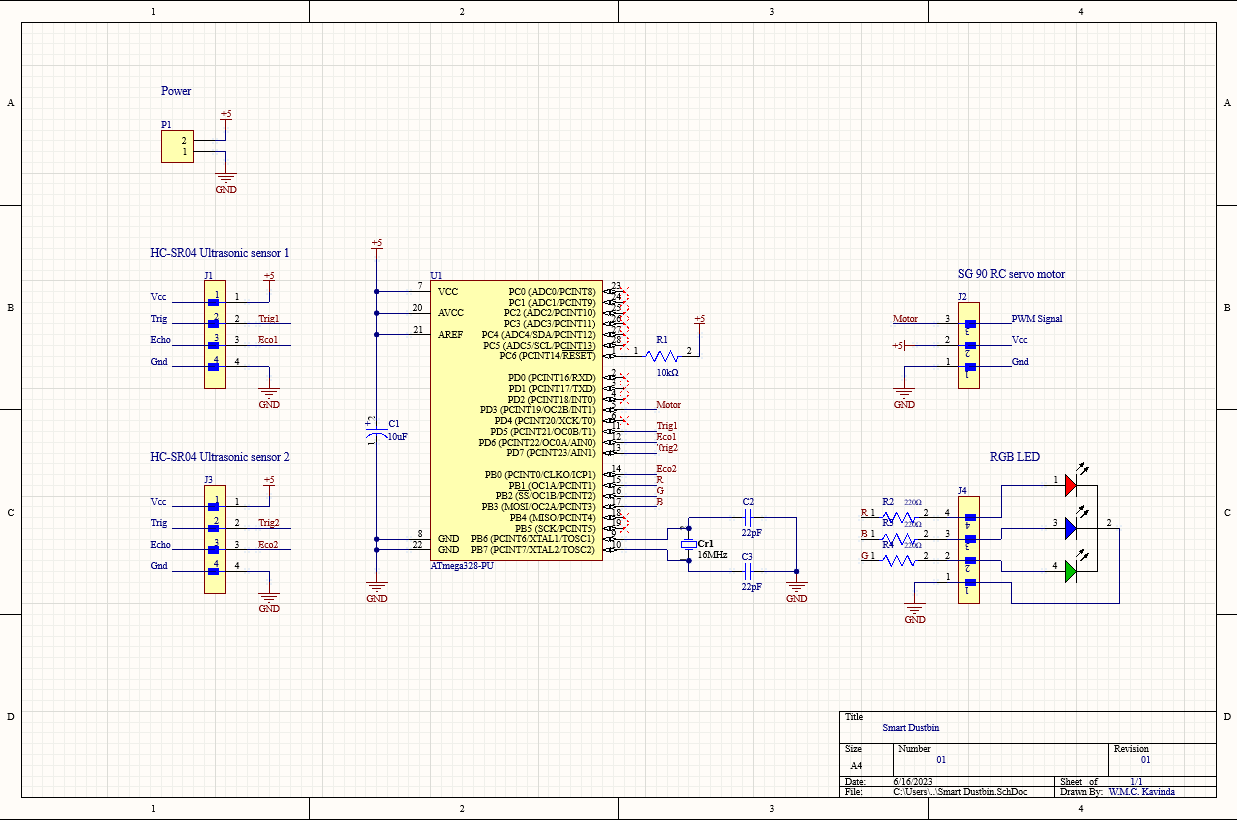
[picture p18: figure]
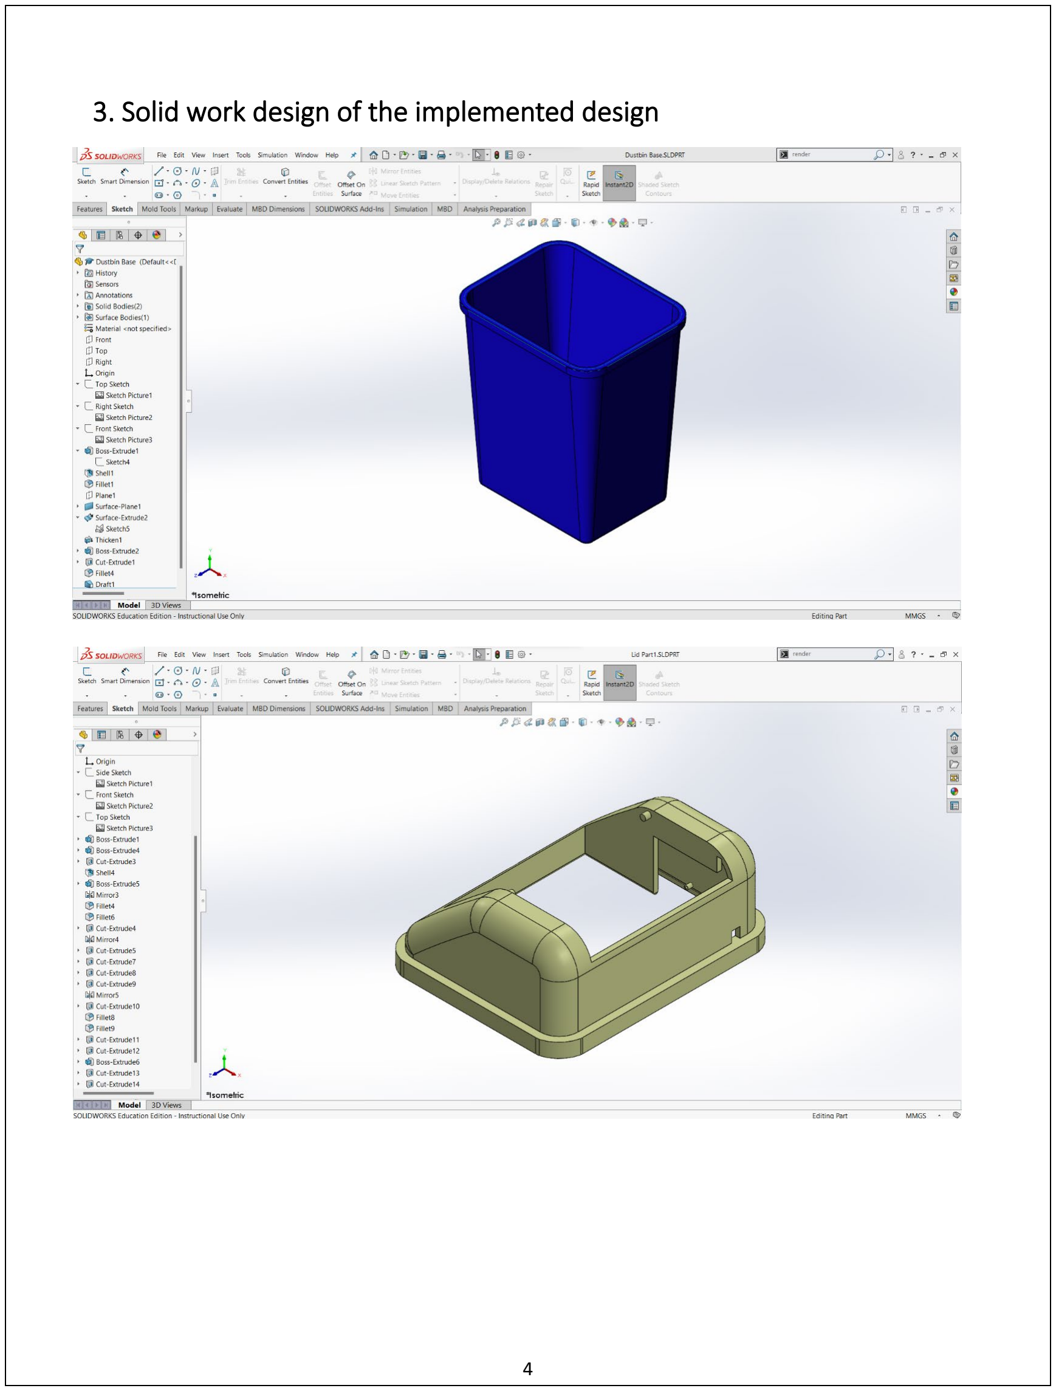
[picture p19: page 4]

### 3. Solid work design of the implemented design

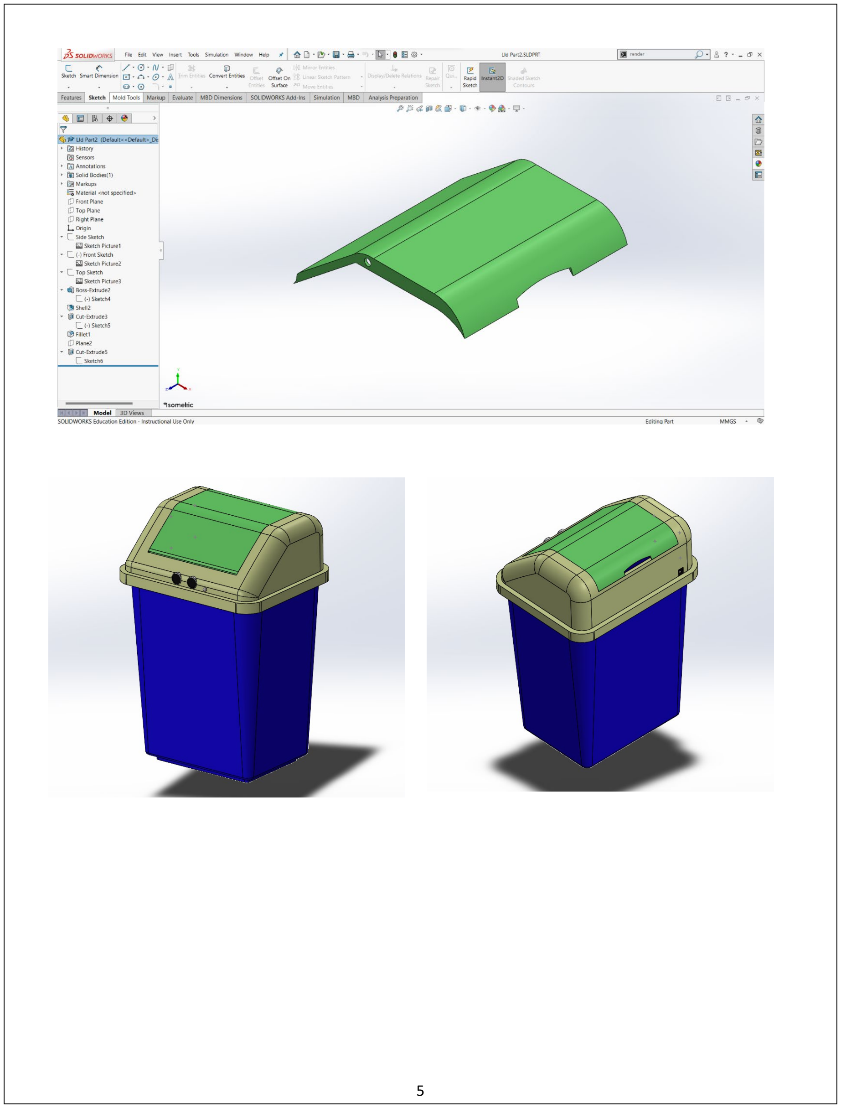
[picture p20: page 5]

### 4. Problems and Improvements

### 4.1 Problems

# 4.1.1 Problems identiied by me

- Dustbin Lid Opening Direcon – The current design of the smart dustbin has the lid opening into the dustbin. This configuraon can obstruct the opening and disposal of waste, making it less convenient for users.

# 4.1.2 Problems identiied by group members

- PCB Placement – The placement of the printed circuit board (PCB) inside the lid poses a potenal problem. This posioning exposes the PCB to the risk of damage or contaminaon from waste, potenally affecng the funconing and lifespan of the smart dustbin.
- Inadequate LED Indicators – The current LED indicators are insufficient in indicang the waste level within the dustbin. Users may face difficules in determining when the dustbin requires emptying, leading to inefficiencies and potenal overflow.

# 4.1.3 Problems identiied by users

- Small Size – The current size of the dustbin is insufficient, liming its capacity and requiring frequent emptying. This inconvenience can be parcularly burdensome in high-traffic areas or busy environments.
- Inadequate External Power Source – The current power source for the smart dustbin, when used in outdoor environments, is not opmal. It may not withstand harsh weather condions or provide a reliable and sustainable power supply, compromising the dustbin's performance and funconality.

### 4.2 Improvements

# 4.2.1 Improvements proposed by group members

- Lid Opening Direcon – Redesign the dustbin lid to open away from the dustbin instead of into it. This modificaon ensures unobstructed access for waste disposal and improves user convenience.
- PCB Relocaon – Move the PCB from inside the lid to a protected and sealed compartment within the dustbin, ensuring its longevity and reliable performance by minimizing the risk of damage or contaminaon.
- OLED Display for Level Indicaon – Incorporate an OLED display on the dustbin's exterior to provide clear and accurate indicaons of the fill level. This display can show precise measurements or visual representaons, enabling users to easily monitor the dustbin's status.
- Incorporaon of Humidity Sensor – Integrate a humidity sensor into the smart dustbin design. This sensor will detect the level of moisture or humidity inside the dustbin, providing valuable informaon about the potenal presence of liquids or wet waste. By detecng high humidity levels, the sensor can alert users to take appropriate measures, such as using absorbent materials or emptying the dustbin promptly to prevent unpleasant odors, leakage, or bacterial growth.

# 4.2.2 Improvements proposed by users

- Batery Power – Ulize bateries as a power source for the smart dustbin, eliminang the need for an external power supply. This ensures portability and independence from external power sources, making the dustbin suitable for outdoor environments without compromising its funconality.
- Increased Size – Enhance the dustbin's size and capacity to accommodate a larger volume of waste, reducing the frequency of empness and providing users with greater convenience.

### 5. Schemac of the improved design

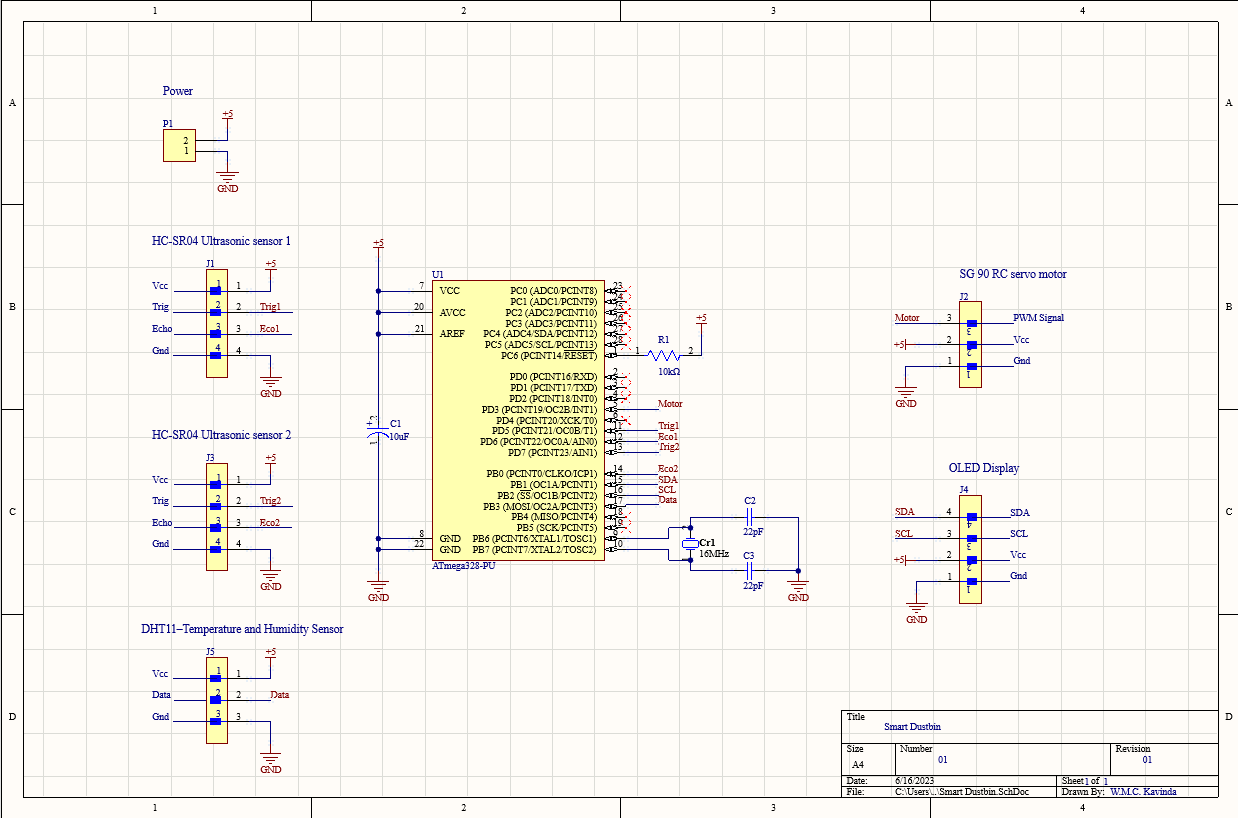
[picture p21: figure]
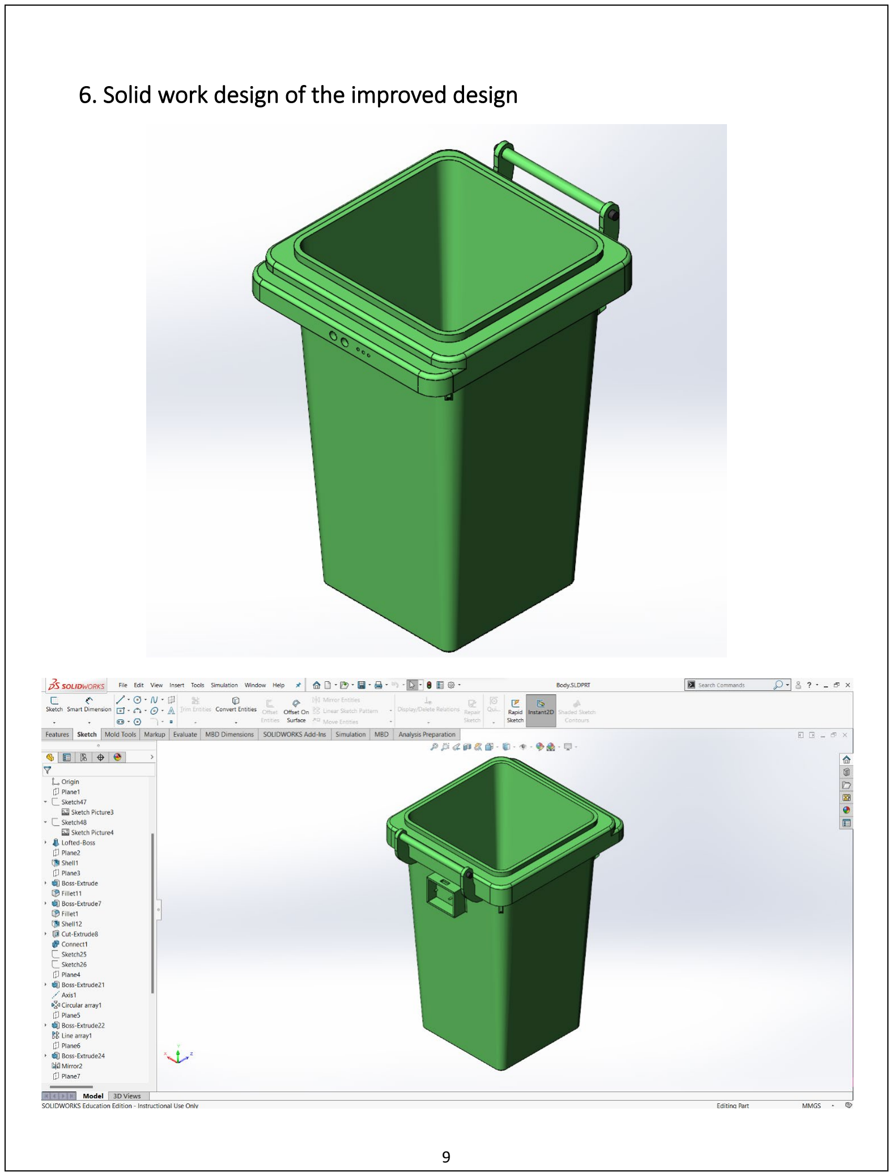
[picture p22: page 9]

### 6. Solid work design of the improved design

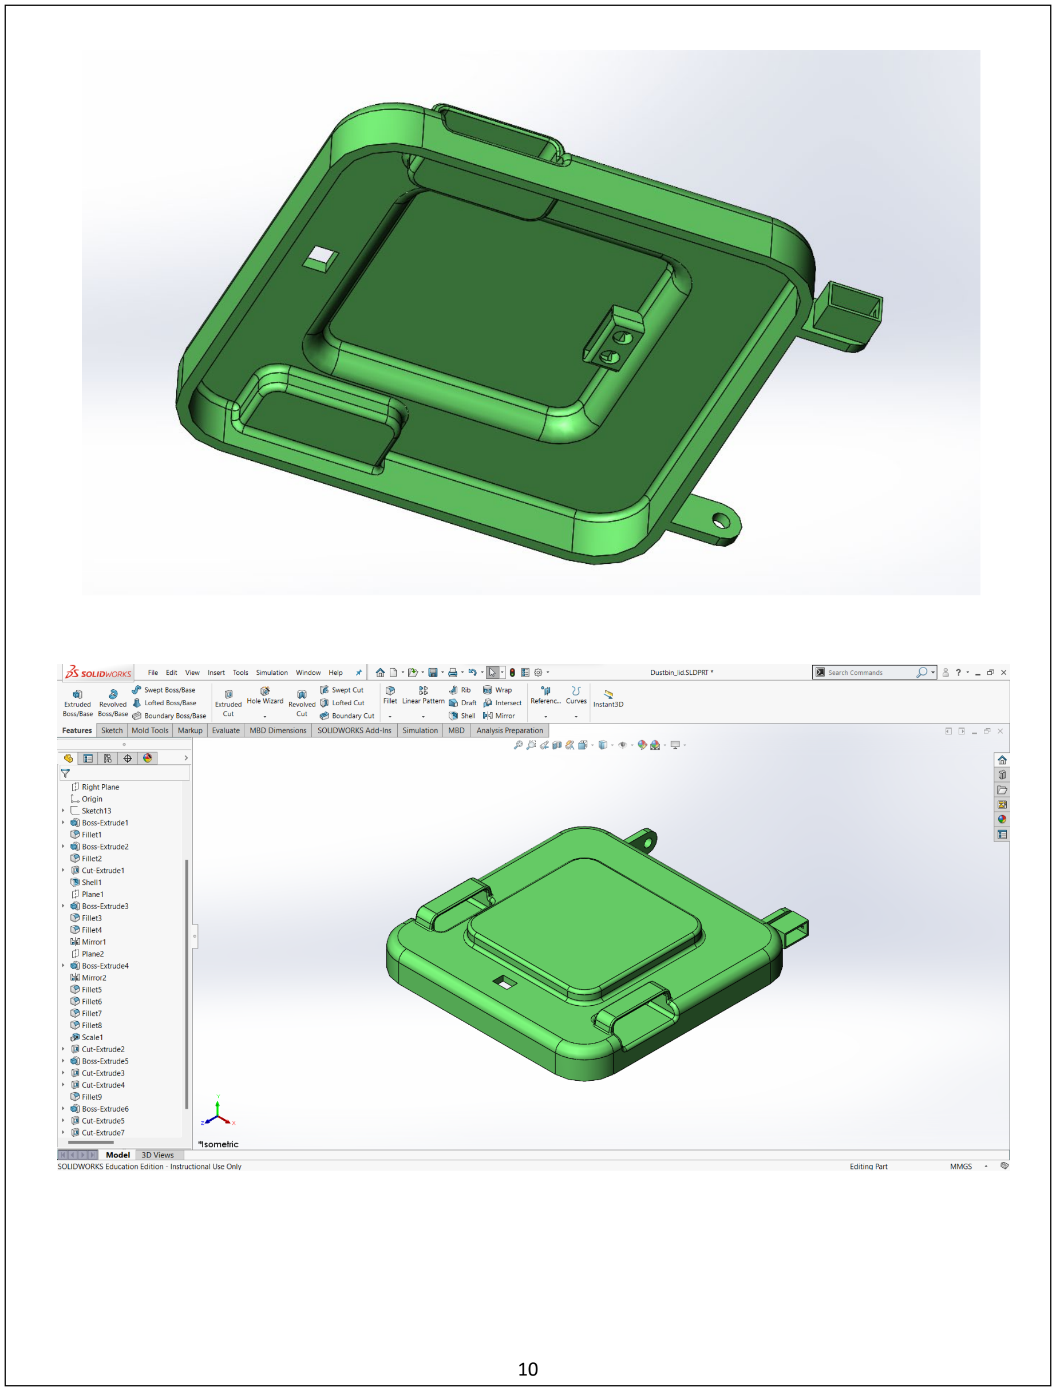
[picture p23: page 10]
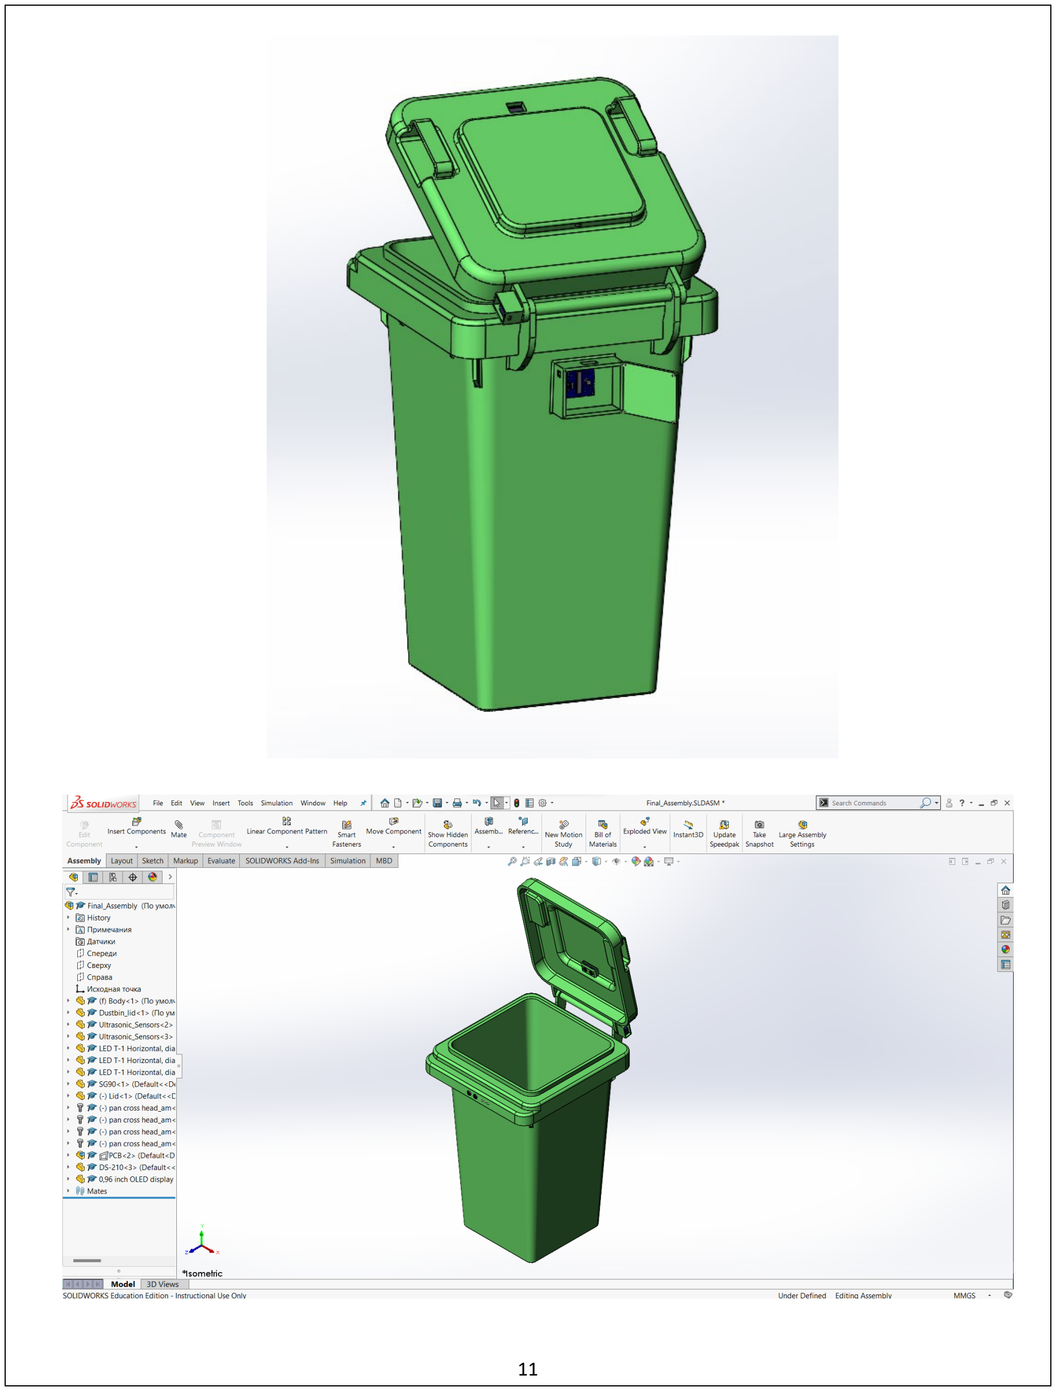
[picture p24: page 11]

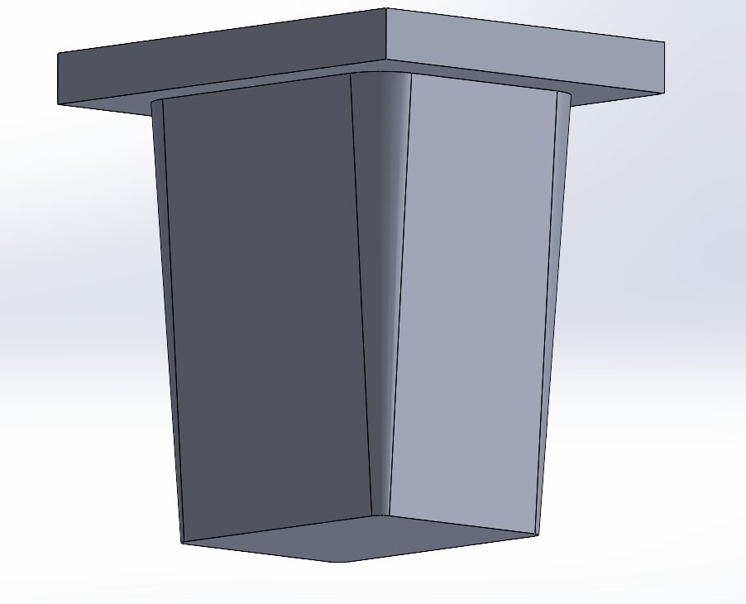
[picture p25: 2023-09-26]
Enclosure Design files/Die and Cavity/Core.png

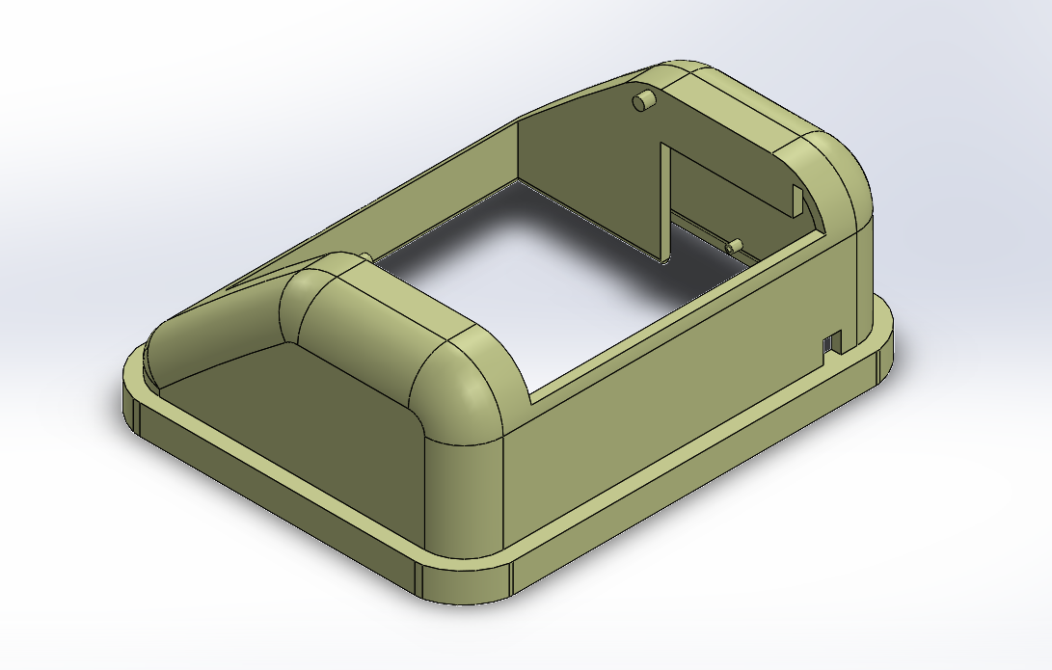
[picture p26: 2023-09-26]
Enclosure Design files/3D Design/Lid Part1.png

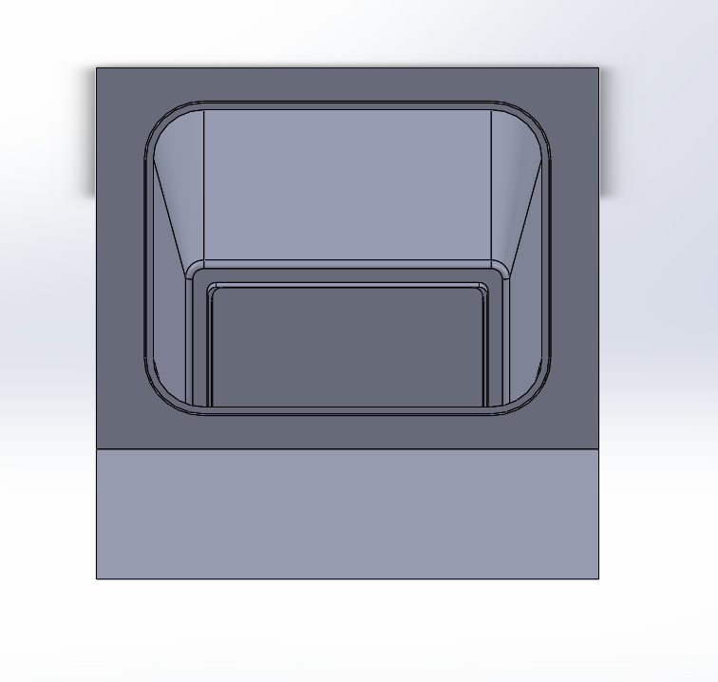
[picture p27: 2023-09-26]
Enclosure Design files/Die and Cavity/Cavity.png

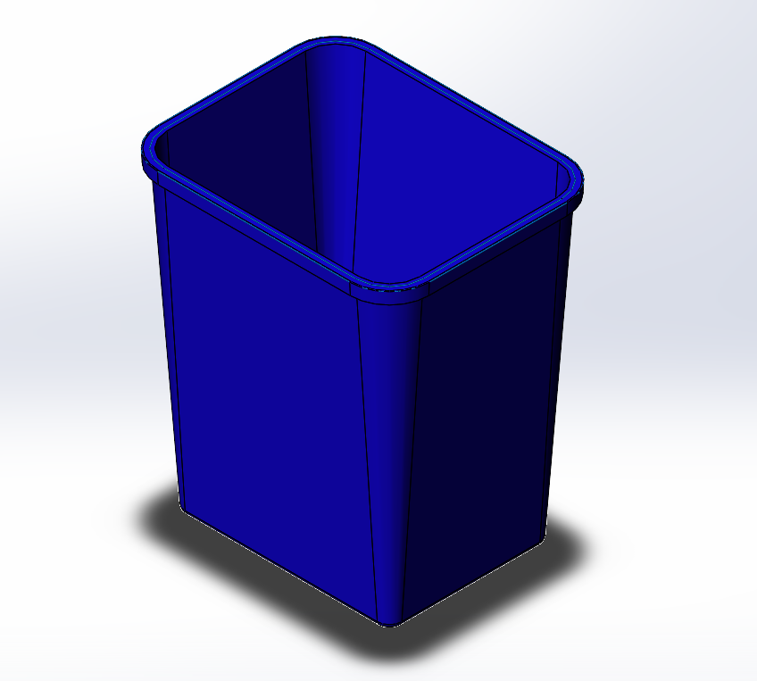
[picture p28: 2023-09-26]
Enclosure Design files/3D Design/Dustbin Base.png

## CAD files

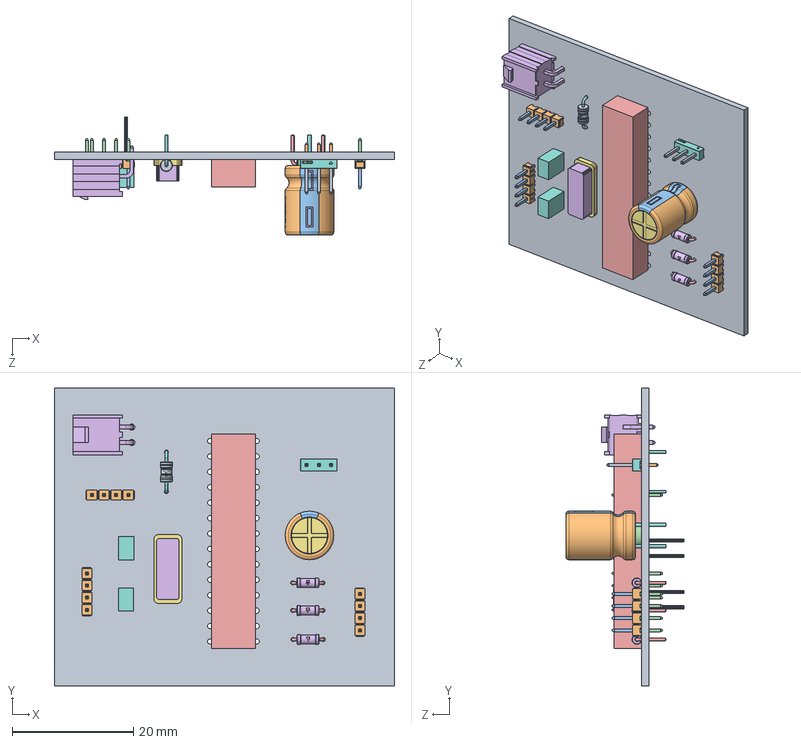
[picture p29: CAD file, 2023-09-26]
Enclosure Design files/3D Design/PCB.SLDASM
56.0 x 49.0 x 19.5 mm
body.step
marking.step
bottom.step
logo.step
polarity_marking.step
top.step
terminal.step
logo-0.step x 3
body-1.step x 12
TMM-104-01-L-D-SM_pins1.step x 12
TMM-104-01-L-D-SM-P-TR_sm_pins2.0004.step x 12
Extruded.step
Extruded-2.step
Extruded-3.step
TMM-103-03-T-S_body.step
TMM-103-03-T-S_pins1.step
TMM-103-03-T-S_pins2.step
Pin1_Triangle.step
Samtec.step
1.step x 3
2.step x 3
3.step x 3
body-4.step
brown_strip.step
black_strip.step
gold_strip.step
orange_strip.step
Conn_Samtec_IPL1-102-01-S-S-RA-K_eec.step
Extruded-5.step x 4
Extruded-6.step x 2

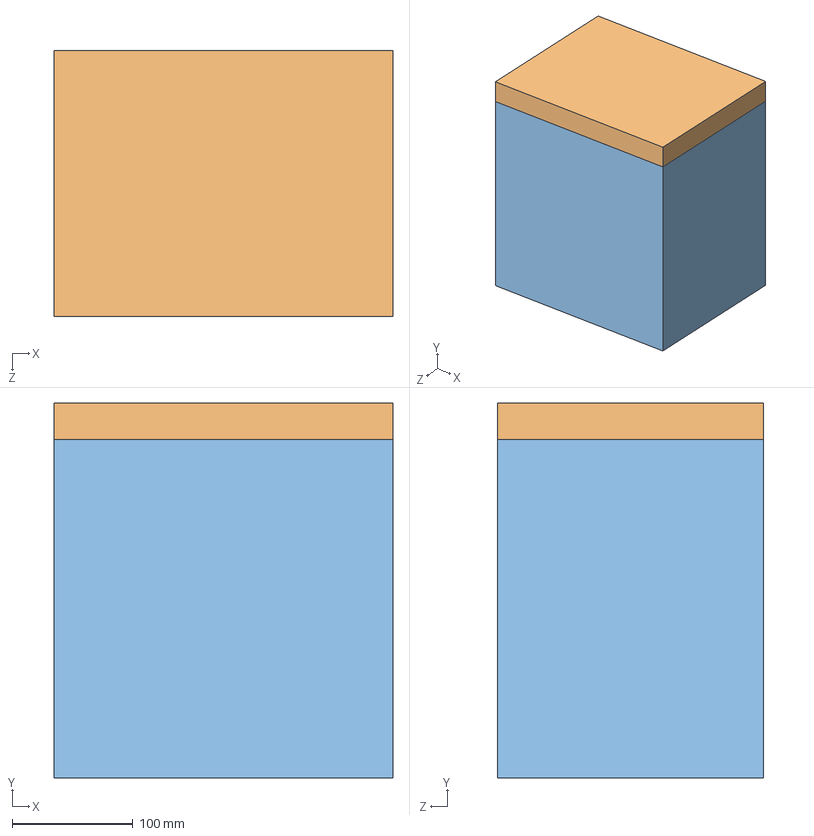
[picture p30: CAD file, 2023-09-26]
Enclosure Design files/Die and Cavity/Die Design.SLDASM
280.0 x 310.0 x 220.0 mm
Core
Cavity

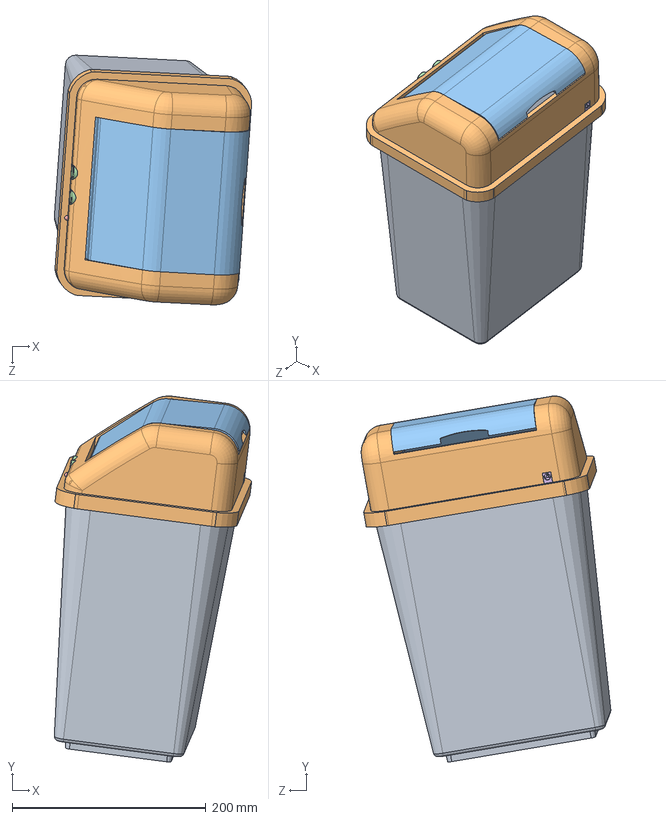
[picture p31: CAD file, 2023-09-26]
Enclosure Design files/3D Design/Assembly.SLDASM
204.0 x 378.2 x 258.1 mm
Dustbin Base
Lid Part1
LId Part2
body.step
marking.step
bottom.step
logo.step
polarity_marking.step
top.step
terminal.step
logo-0.step x 3
body-1.step x 12
TMM-104-01-L-D-SM_pins1.step x 12
TMM-104-01-L-D-SM-P-TR_sm_pins2.0004.step x 12
Extruded.step
Extruded-2.step
Extruded-3.step
TMM-103-03-T-S_body.step
TMM-103-03-T-S_pins1.step
TMM-103-03-T-S_pins2.step
Pin1_Triangle.step
Samtec.step
1.step x 3
2.step x 3
3.step x 3
body-4.step
brown_strip.step
black_strip.step
gold_strip.step
orange_strip.step
Conn_Samtec_IPL1-102-01-S-S-RA-K_eec.step
Extruded-5.step x 4
Extruded-6.step x 2
Ultrasonic_Sensors
LED T-1 Horizontal, dia 5mm, RGB
DS-210
Part12^Assembly

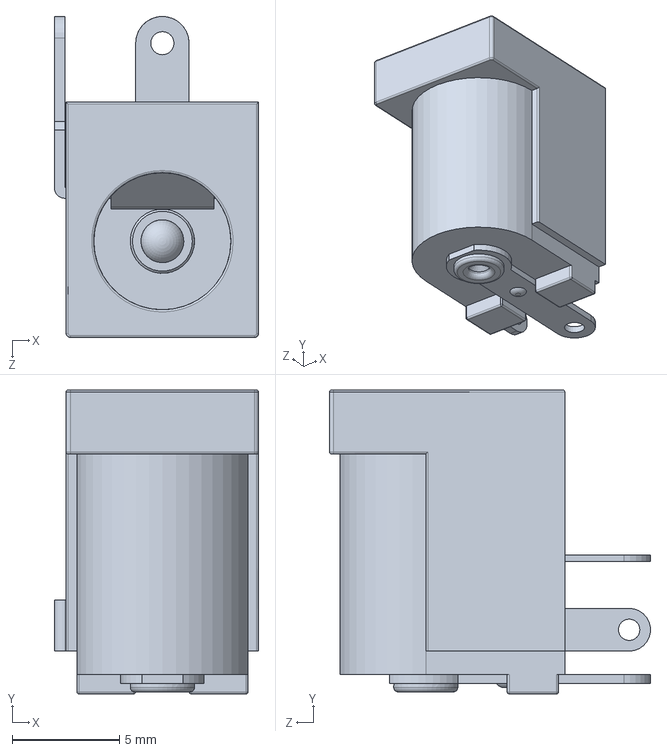
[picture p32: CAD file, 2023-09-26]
Enclosure Design files/3D Design/DS-210.SLDPRT
9.55 x 14.2 x 15.0 mm

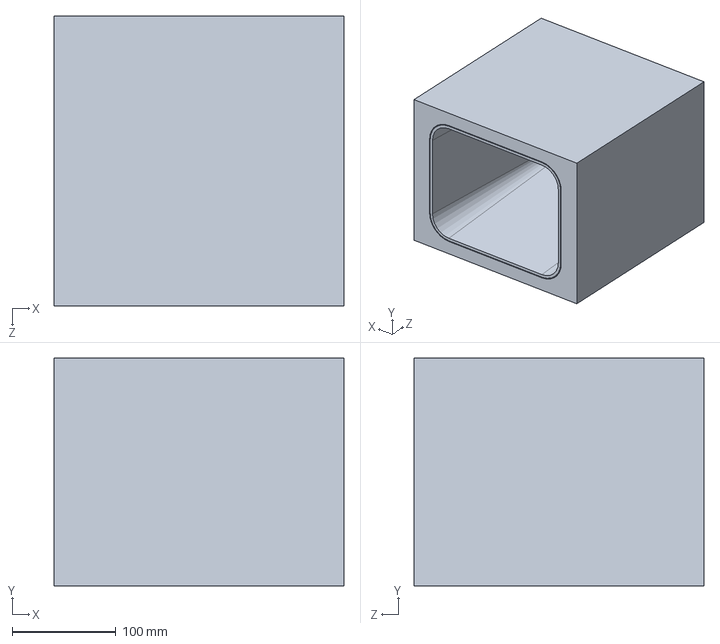
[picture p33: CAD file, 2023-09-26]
Enclosure Design files/Die and Cavity/Cavity.SLDPRT
280.0 x 220.0 x 280.0 mm

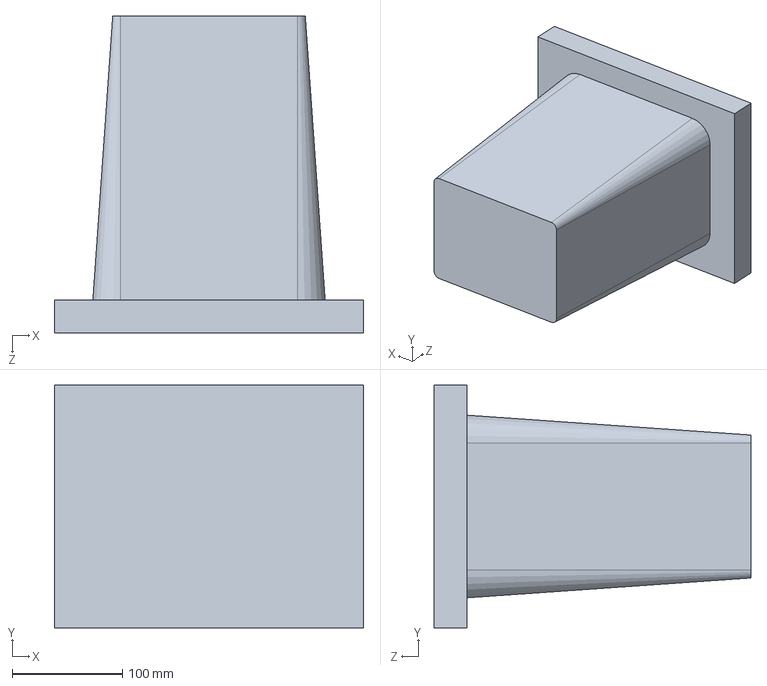
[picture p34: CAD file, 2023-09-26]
Enclosure Design files/Die and Cavity/Core.SLDPRT
280.0 x 220.0 x 287.0 mm

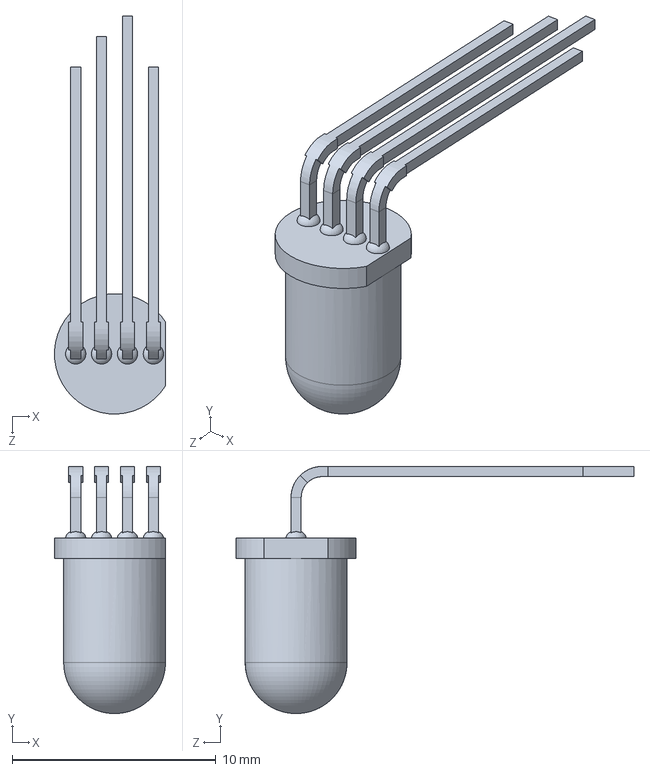
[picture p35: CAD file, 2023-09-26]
Enclosure Design files/3D Design/LED T-1 Horizontal, dia 5mm, RGB.SLDPRT
5.45 x 12.1 x 19.5 mm

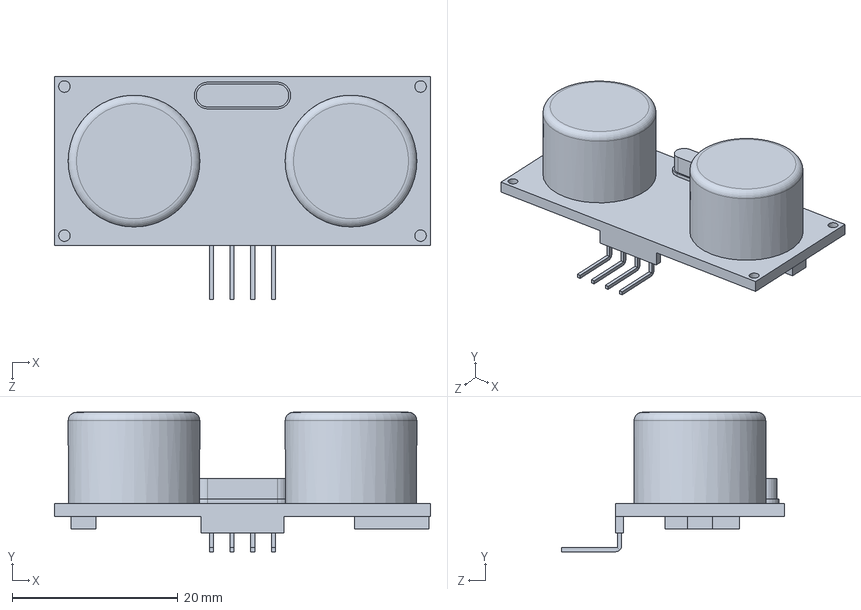
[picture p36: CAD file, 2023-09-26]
Enclosure Design files/3D Design/Ultrasonic_Sensors.SLDPRT
45.4 x 16.9 x 26.9 mm

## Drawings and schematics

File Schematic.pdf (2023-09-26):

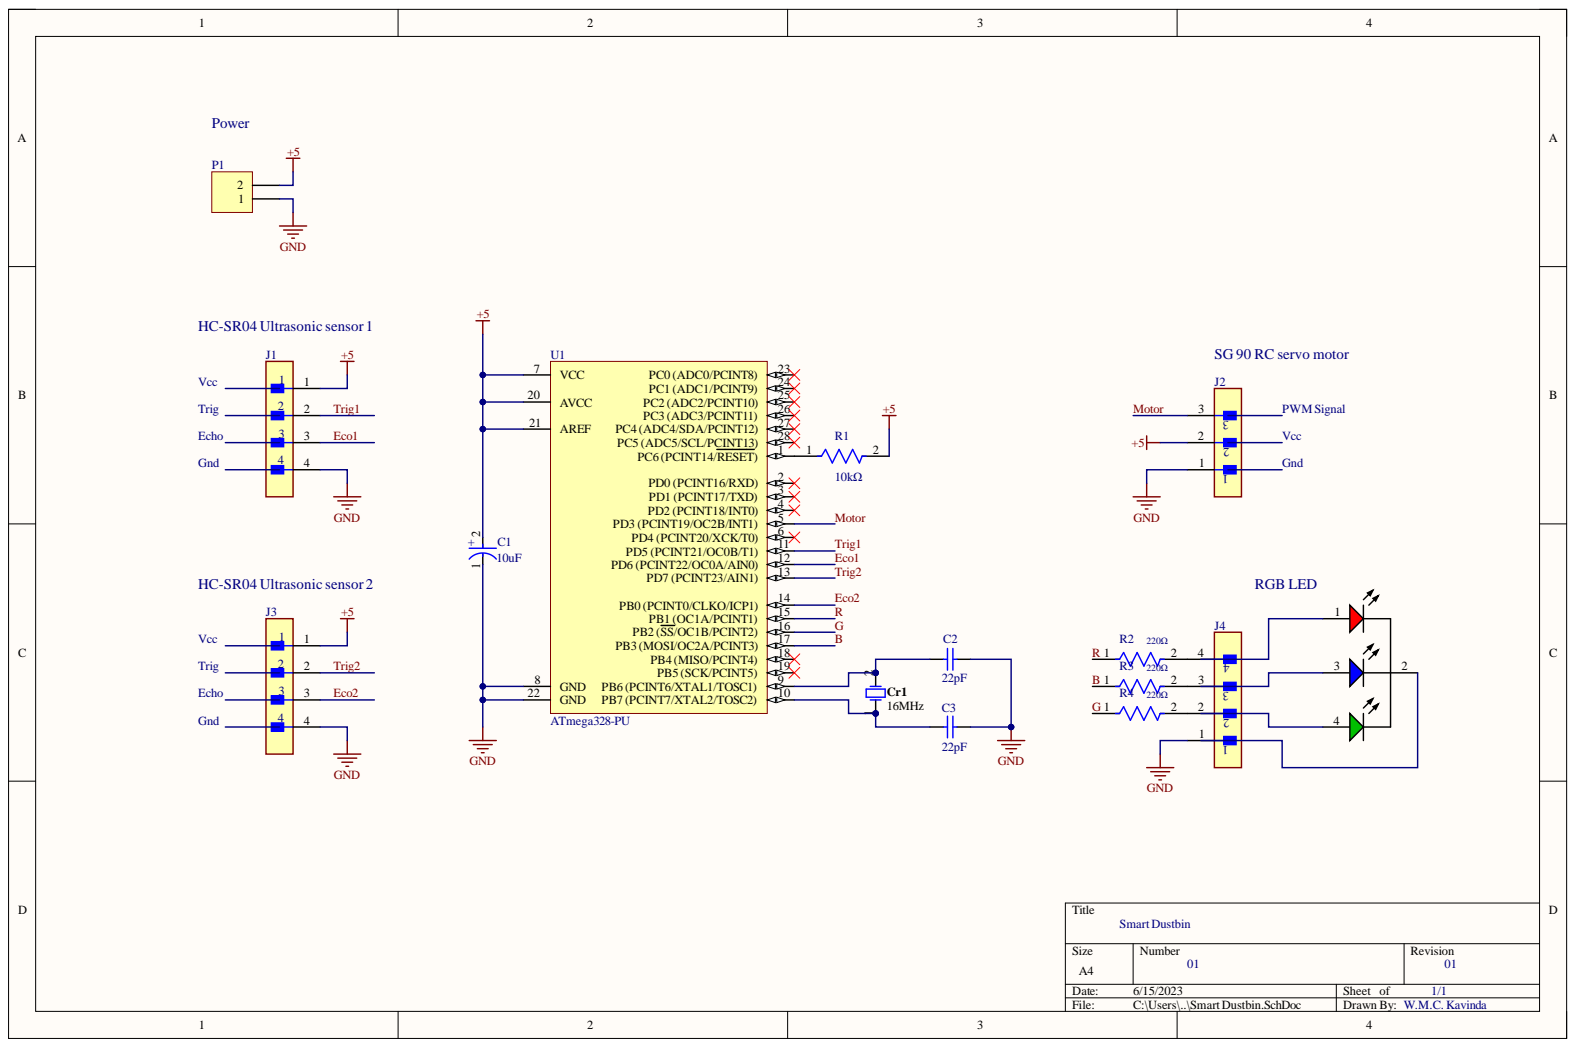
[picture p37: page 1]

SG 90 RC servo motor

Size A4 | Number 01 | Revision 01

Date: 6/15/2023 | Sheet of 1/1
File: C:\Users\..\Smart Dustbin.SchDoc | Drawn By: W.M.C. Kavinda
